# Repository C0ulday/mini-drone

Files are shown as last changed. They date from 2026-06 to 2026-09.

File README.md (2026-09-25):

# Micro Drone & Custom Remote

A small quadcopter and its own remote, built from scratch: flight electronics,
brushed-motor driving, a wireless link, and power. 

## What it is

A micro / tiny-whoop-class drone built end to end to learn the whole stack: motor
driving, real-time control, a radio link, power, and hand assembly.

## Hardware

| Category | Details |
|---|---|
| **MCU (drone & remote)** | ESP32-C3 Super Mini – RISC-V 32‑bit @ 160 MHz, WiFi + BLE 5.0 |
| **Motors** | 4x coreless brushed DC motors (8 × 16 mm), ~5200 RPM, with propellers |
| **Motor drivers** | 4x AO3400 N‑channel MOSFETs (SOT‑23) – one per motor, low‑side PWM switching, mounted on SOT23‑to‑DIP breakout boards for prototyping |
| **Flight battery** | 1S LiPo 200 mAh – 3.7 V – 45C (PH2.0 connector) |
| **Charger** | ISDT PD60 (1‑4S LiPo compatible) |
| **Storage** | 64 GB micro SD card (logging / config) |
| **Mechanics** | M2.5 brass standoffs; prototype frame from wooden sticks (3D‑printed frame designed, print pending) |
| **Bench power supply** | 12 V – 3 A DC adapter (for bench testing) |

## How it works

- The ESP32-C3 on the drone runs the flight firmware and hosts the wireless link
  (WiFi / BLE) to the remote.
- Four PWM channels drive the AO3400 MOSFETs (low-side), setting the speed of each
  coreless motor; a flyback diode protects each channel.
- A second ESP32-C3 is the remote: it reads the control inputs and sends commands
  over the link.
- The 1S LiPo powers the motors; the ESP32 runs from its onboard regulator. A 12 V
  bench adapter is used while testing on the desk.
- (feature i want to add): an electromagnet, switched by a MOSFET, for a payload pick-and-release
  experiment (separate power domain).

## Circuit

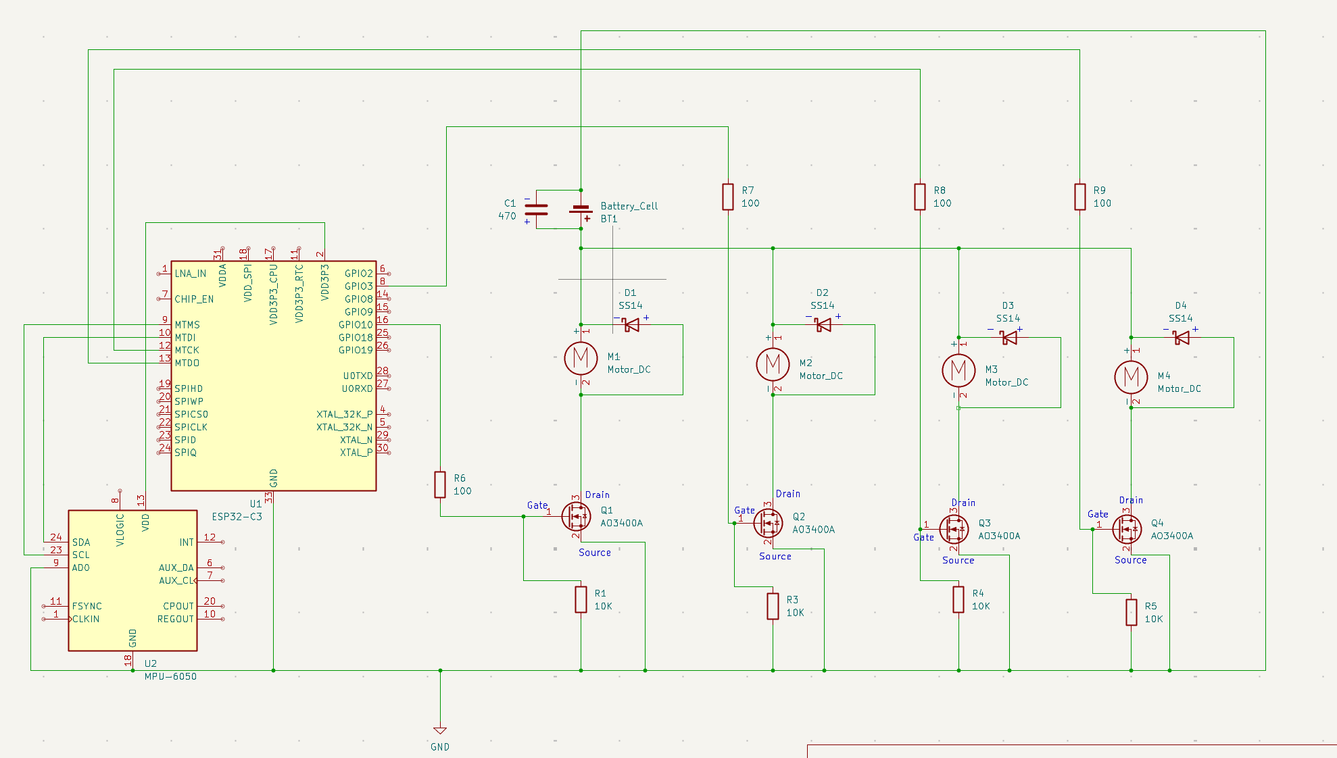
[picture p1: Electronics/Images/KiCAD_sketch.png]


## Drone's frame
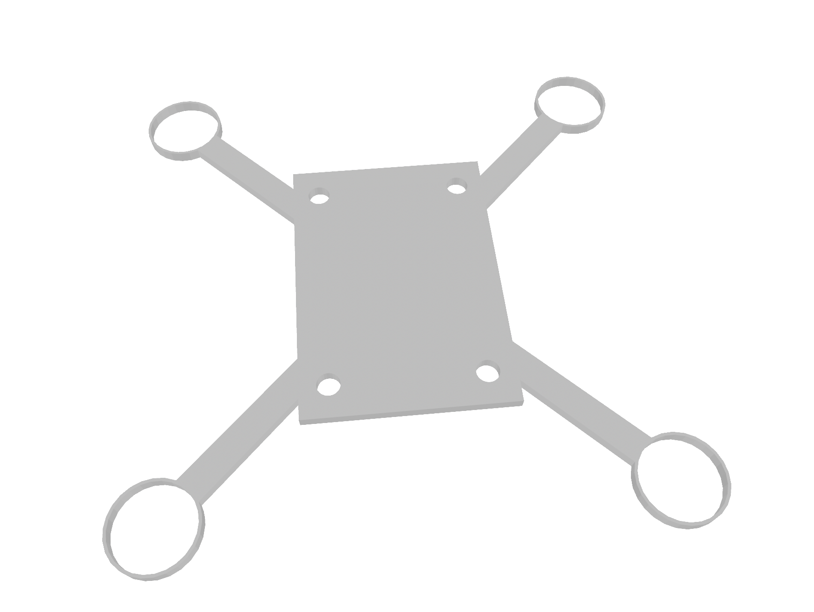
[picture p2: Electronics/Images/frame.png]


## Controlling one moter and his driver

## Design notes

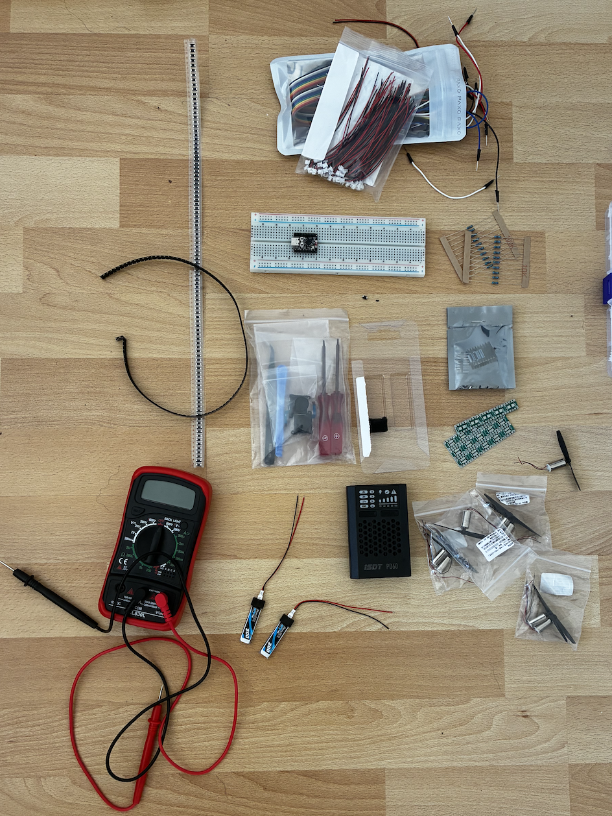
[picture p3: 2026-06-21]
Electronics/Images/elec1.png

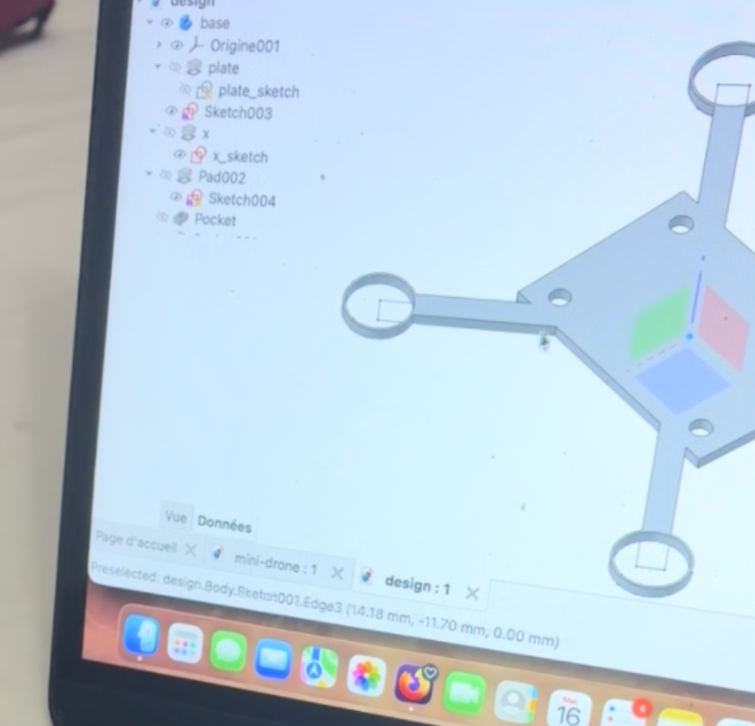
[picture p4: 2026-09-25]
Electronics/Images/DRONE-SUPPORT.png

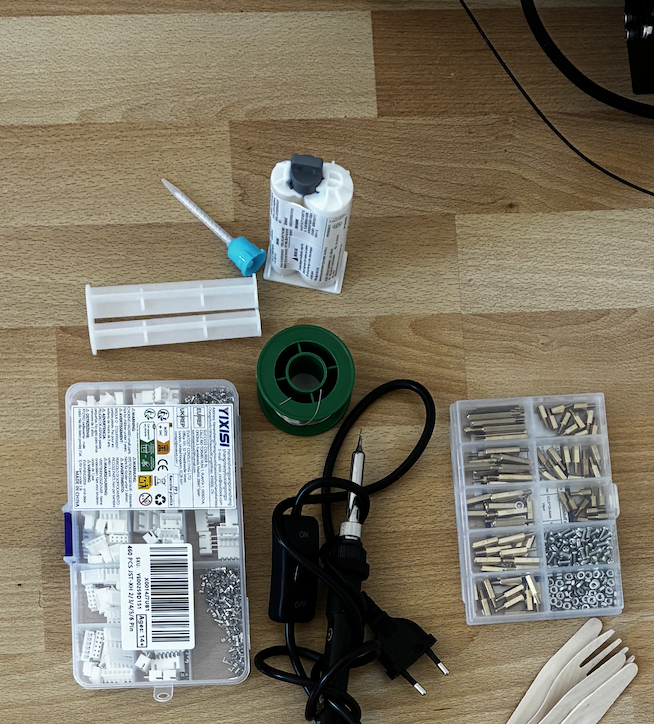
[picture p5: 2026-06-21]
Electronics/Images/elec2.png

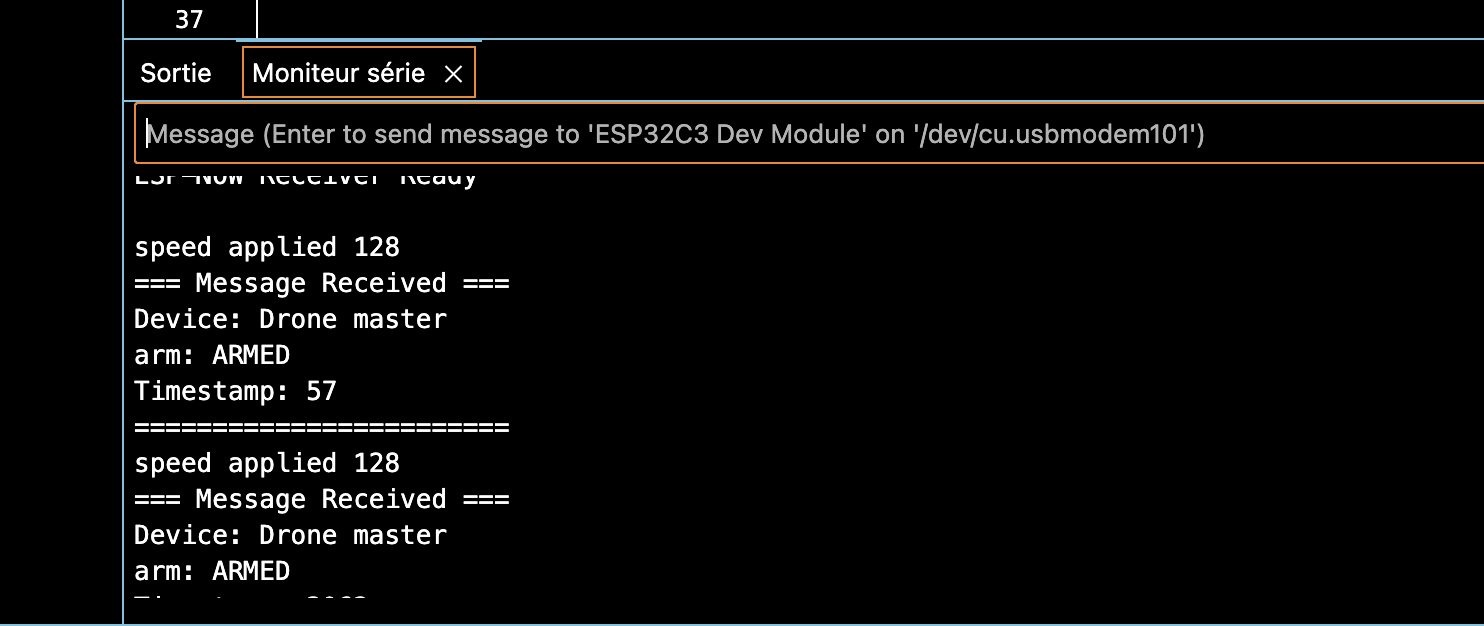
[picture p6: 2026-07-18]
Code/captures/slave_response.png

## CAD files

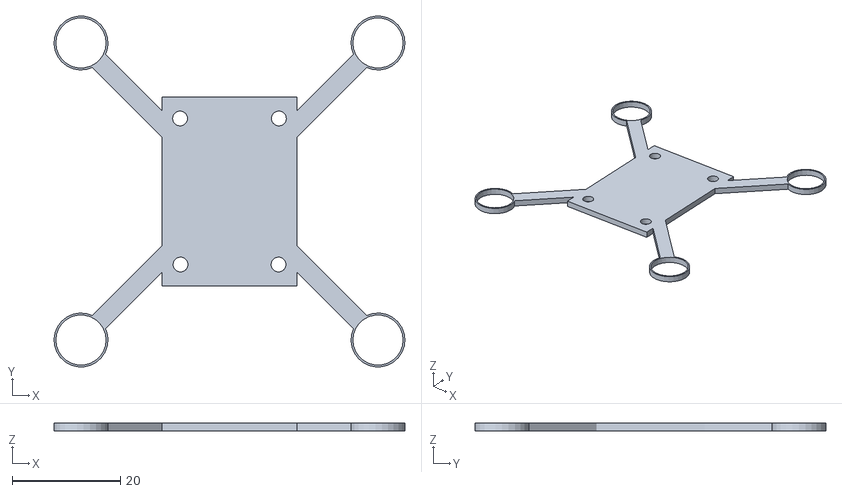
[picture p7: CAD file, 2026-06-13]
Design/bottom.stl
65.0 x 65.0 x 1.50

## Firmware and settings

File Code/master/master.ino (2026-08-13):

#include <esp_now.h>
#include <WiFi.h>

#define CHANNEL 1
#define THROTTLE_PIN 1
#define YAW_PIN 2
#define ROLL_PIN 3
#define PITCH_PIN 4
#define ADC_MAX 4095


esp_now_peer_info_t slave;
uint8_t last_seq = 0;

// message structure
typedef struct __attribute__((packed)) { // pour éviter des trous dans la structure
                                        // mets les données les unes à côté de l'autre
    uint8_t magic_byte; // premier byte pour vérifier intégrité du message
    uint8_t seq;        // numéro du message
    uint8_t motor_speed;     // Vitesse du moteur (0 à 255) 

    uint8_t roll;
    uint8_t pitch;
    uint8_t yaw;

    bool arm;               // true = moteur autorisé, false = coupé
    unsigned long timestamp; // pour vérifier la vieillesse des messages
    uint8_t crc;   // checksum
} Message;

Message incomingMessage;

uint8_t broadAddr[6] = {0xFF, 0xFF, 0xFF, 0xFF, 0xFF, 0xFF};

// if master sent the message
void OnDataSent(const esp_now_send_info_t *tx_info, esp_now_send_status_t status){
  Serial.print("sent...");
  Serial.println(status == ESP_NOW_SEND_SUCCESS ? "Success" : "Failed");
}

// setting up the master
void setup() {
  // put your setup code here, to run once:
  Serial.begin(115200); // baud rate
  WiFi.mode(WIFI_STA); // station mode

  
  if (esp_now_init() != ESP_OK){
    Serial.println("error init ESP_NOW");
    return;
  } 

  esp_now_register_send_cb(OnDataSent);
  memcpy(slave.peer_addr, broadAddr, 6);
  slave.channel = CHANNEL;
  slave.encrypt = 0;

  if(esp_now_add_peer(&slave)== ESP_OK) {
    Serial.println("peer added...");
  } else {
    Serial.println("peer not added...");
    return;
  }

  
}

uint8_t checkSum(uint8_t* data, size_t len) {

    uint8_t checksum = 0;
    for(size_t i = 0 ; i < len - 1 ; i++ ) {
        checksum += data[i];
    }
    return checksum;
}


void loop() {

  incomingMessage.magic_byte = 0xC7;
  incomingMessage.timestamp = millis();

  int adc_value = analogRead(THROTTLE_PIN);
  int yaw_value = analogRead(YAW_PIN);
  int roll_value = analogRead(ROLL_PIN);
  int pitch_value = analogRead(PITCH_PIN);

  incomingMessage.motor_speed = map(adc_value,0,ADC_MAX,0,255);

  incomingMessage.pitch =map(pitch_value,0,ADC_MAX,0,255);
  incomingMessage.roll =map(roll_value,0,ADC_MAX,0,255);
  incomingMessage.yaw =map(yaw_value,0,ADC_MAX,0,255);

  incomingMessage.arm = true;
  incomingMessage.seq = last_seq +1;

  incomingMessage.crc = checkSum((uint8_t*)&incomingMessage, sizeof(incomingMessage));


  esp_err_t result = esp_now_send(slave.peer_addr, (uint8_t*)&incomingMessage, sizeof(incomingMessage));

  if (result == ESP_OK) {

    Serial.printf("sent (seq=%d, gas=%d, roll=%d, pitch=%d, yaw=%d)\n",
                      incomingMessage.seq,
                      incomingMessage.motor_speed,
                      incomingMessage.roll,
                      incomingMessage.pitch,
                      incomingMessage.yaw);

    Serial.println("sent");
    last_seq = incomingMessage.seq;

  } else {
    Serial.println("error");
  }

  delay(20);


}

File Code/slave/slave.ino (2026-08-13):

#include <esp_now.h>
#include <WiFi.h>


#define MOTOR_PIN 3
#define PWM_FREQ 20000
#define PWM_RES  8          // 8 bits → 0..255

uint8_t last_seq;
unsigned long last_Rx = 0;


typedef struct __attribute__((packed)) { // pour éviter des trous dans la structure
                                        // mets les données les unes à côté de l'autre
    uint8_t magic_byte; // premier byte pour vérifier intégrité du message
    uint8_t seq;        // numéro du message
    uint8_t motor_speed;     // Vitesse du moteur (0 à 255) 

    uint8_t roll;
    uint8_t pitch;
    uint8_t yaw;

    bool arm;               // true = moteur autorisé, false = coupé
    unsigned long timestamp; // pour vérifier la vieillesse des messages
    uint8_t crc;   // checksum
} Message;

Message incomingMessage;




uint8_t checkSum(uint8_t* data, size_t len) {

    uint8_t checksum = 0;
    for(size_t i = 0 ; i < len - 1 ; i++ ) {
        checksum += data[i];
    }
    return checksum;
}

void launchMotor(){

    ledcWrite(MOTOR_PIN,incomingMessage.motor_speed);
    Serial.printf("speed applied %d\n",incomingMessage.motor_speed);

}

void stopMotor(){

    ledcWrite(MOTOR_PIN,0);
    Serial.printf("motor stopped\n");

}



void setup() {

    Serial.begin(115200);

    WiFi.mode(WIFI_STA);

    Serial.println(WiFi.macAddress());
    
    if (esp_now_init() != ESP_OK) {

        Serial.println("Error initializing ESP-NOW\n");

        return;

    }

    ledcAttach(MOTOR_PIN, PWM_FREQ, PWM_RES);
    stopMotor();

    esp_now_register_recv_cb(OnDataRecv);

    Serial.println("ESP-NOW Receiver Ready\n");

}



void OnDataRecv(const esp_now_recv_info* mac, const uint8_t *incomingData, int len) {

    if (len != sizeof(Message)) {
        Serial.printf("Invalid size !\n");
        return;
    }

    Message temp;
    memcpy(&temp, incomingData, sizeof(temp));

    if(temp.magic_byte != 0xC7) {
        Serial.printf("Invalid magic byte !\n");
        return;
    }

    if(temp.crc != checkSum((uint8_t*)&temp, sizeof(temp))) {
        Serial.printf("Corrupted message, invalid checksum !\n");
        return;
    }

    if (last_seq !=0 && temp.seq != (last_seq+1)) {
        Serial.printf("Packets loss !\n");
    }
    // On peut désormais copier dans la structure finale
    memcpy(&incomingMessage, incomingData, sizeof(incomingMessage));
    last_Rx = millis();
    last_seq = incomingMessage.seq;

}



void loop() {
    
    if(last_Rx !=0 && millis() - last_Rx  > 300) {
        //Serial.println("connection lost...\n");
        stopMotor();
        return;
    }
    
    if(!incomingMessage.arm) {
        stopMotor();
    } else {
        launchMotor();
    } 


    delay(10);

}

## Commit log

2026-06-12 bottom design
    [bottom.stl]
2026-06-13 new bottom part
    [bottom.stl]
2026-06-18 Revise README for Micro Drone project
    Updated project description and details for the Micro Drone and Custom Remote, including hardware specifications, functionality, current status, and tools used.
2026-07-15 Resolution conflit : suppression de .DS_Store
2026-07-17 adding motor control
2026-07-18 correcting frequency + timestamp message verif
    [master.ino, slave.ino]
2026-08-13 docs : schema kicad corrigé
    [master.ino, slave.ino]
2026-09-25 Add additional circuit images to README
2026-09-25 Update circuit images in README
    Removed two circuit images and added a new image for drone support.
2026-09-25 Add section for Drone's frame in README
2026-09-25 Update drone frame image in README
2026-10-15 add kicad's project
